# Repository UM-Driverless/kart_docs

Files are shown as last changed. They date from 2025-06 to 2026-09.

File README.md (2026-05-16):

# kart-docs

Documentation for the autonomous KART project.

📘 Live site: <https://um-driverless.github.io/kart-docs/>  
🧠 Main source: [Notion Kart Documentation](https://www.notion.so/KART-1b378747314380acb23ee354a4a4c4c7)

Built with [MkDocs](https://www.mkdocs.org/) using the [Material theme](https://squidfunk.github.io/mkdocs-material/).

---

## (Beta) Automated Installation
Just run `install.sh` in Linux or macOS:

## 🔧 Setup (using uv)

Install uv:

```bash
curl -LsSf https://astral.sh/uv/install.sh | sh
```

For other installation methods, see [uv documentation](https://docs.astral.sh/uv/getting-started/installation/).

---

Clone the repo and set up the project:

```bash
git clone git@github.com:UM-Driverless/kart-docs.git
cd kart-docs
uv sync
uv run playwright install --force chrome
```

This:
- Creates a virtual environment and installs dependencies
- Downloads a headless Chrome browser for PDF export

---

## ✅ Preview locally

```bash
uv run mkdocs serve
```
You can then access the documentation in your web browser, usually at `http://127.0.0.1:8000`.

To test the build before pushing (recommended):

```bash
uv run mkdocs build --strict
# Output: site/
```

The `--strict` flag will catch errors like broken links, missing files, and invalid configuration - the same checks that run in CI.

---

## 🚀 Deployment

Deployment to GitHub Pages happens automatically via GitHub Actions when you push to the `main` branch.

The workflow will:
1. Build the documentation with `--strict` flag
2. Deploy to GitHub Pages if the build succeeds
3. Site will be available at: https://um-driverless.github.io/kart-docs/

### Manual deployment (alternative)

If needed, you can still deploy manually:

```bash
uv run mkdocs gh-deploy
```

---

## 🤖 LLM-Friendly Documentation

This documentation includes LLM-optimized formats following the [llms.txt standard](https://llmstxt.org/):

- **llms.txt**: Sitemap-style overview of all documentation pages
- **llms-full.txt**: Complete documentation content in one consumable file

These files are automatically generated during the build process and are available at:
- Live site: https://um-driverless.github.io/kart-docs/llms.txt
- Live site: https://um-driverless.github.io/kart-docs/llms-full.txt

### Manual Generation

To manually generate the LLM files:

```bash
uv run python generate_llm_files.py
```

---

## 📊 BOM Reports & Parts Management

This documentation includes advanced BOM (Bill of Materials) management features:

### Automatic Features (Built into MkDocs)

When you build the docs, the following happens automatically:

- **Searchable parts table** - Dynamically generated from all `bom.yaml` files
- **Cost summaries** - Total costs by assembly, status, and criticality
- **Filterable by** - Assembly, status, category, or search text
- **Sortable columns** - Click any column header to sort

These features are enabled by the `generate_bom_hook.py` MkDocs hook.

### Manual BOM Reports

Generate comprehensive reports (JSON + CSV):

```bash
./generate_bom_reports.sh
```

Or manually:

```bash
uv run python scripts/aggregate_bom.py --output-dir reports/bom --format both
```

**Outputs:**
- `reports/bom/bom_complete_report.json` - Complete data (costs, suppliers, status)
- `reports/bom/bom_assembly_costs.csv` - Cost breakdown by assembly
- `reports/bom/bom_all_components.csv` - All components in spreadsheet format

### Adding Components

1. Navigate to appropriate assembly folder: `docs/assembly/steering/`
2. Edit `bom.yaml` file
3. Add component using YAML format
4. Component automatically appears in searchable table on next build

See the **[BOM page](https://um-driverless.github.io/kart-docs/bom/)** for complete documentation and searchable parts table.

---

## 📟 PDF Export (optional)

PDF export is disabled by default to speed up builds. To export PDFs explicitly:

```bash
EXPORT_PDF=true uv run mkdocs build
# Outputs: site/pdf/kart-documentation.pdf
```

---

## 🗂 Branch structure

- `main` → Markdown source (all edits go here)
- `gh-pages` → Legacy deployment branch (can be deleted if using GitHub Actions)

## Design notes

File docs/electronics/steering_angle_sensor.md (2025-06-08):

# Steering Angle Sensor
Sensor used is the cheap AS5600
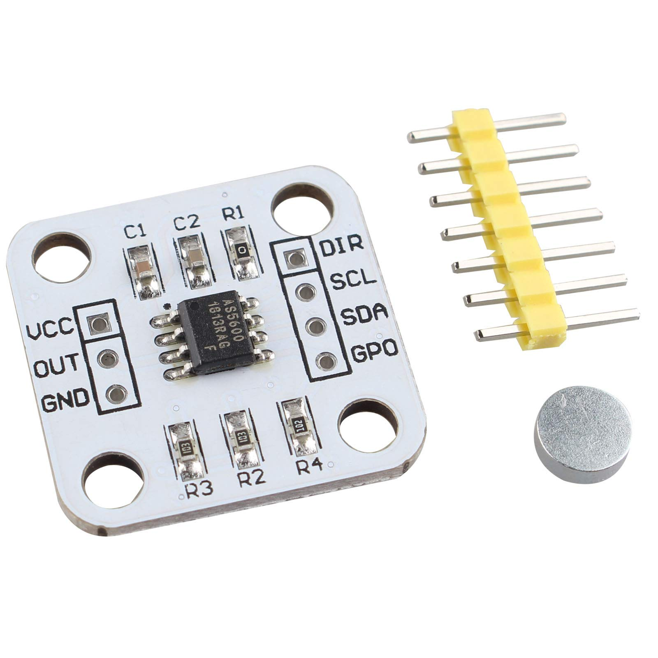
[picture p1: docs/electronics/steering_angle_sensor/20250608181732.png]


Intended for use with a diametrically magnetized magnet, but works with a normal one turned 90 degrees too.
It may be a good idea to find bigger neodymium diametric magnets.

Repo with basic code to read the steering angle sensor (Arduino HAL with VSCode Platformio, no IDE): https://github.com/rubenayla/bluepill-angle-arduino.git

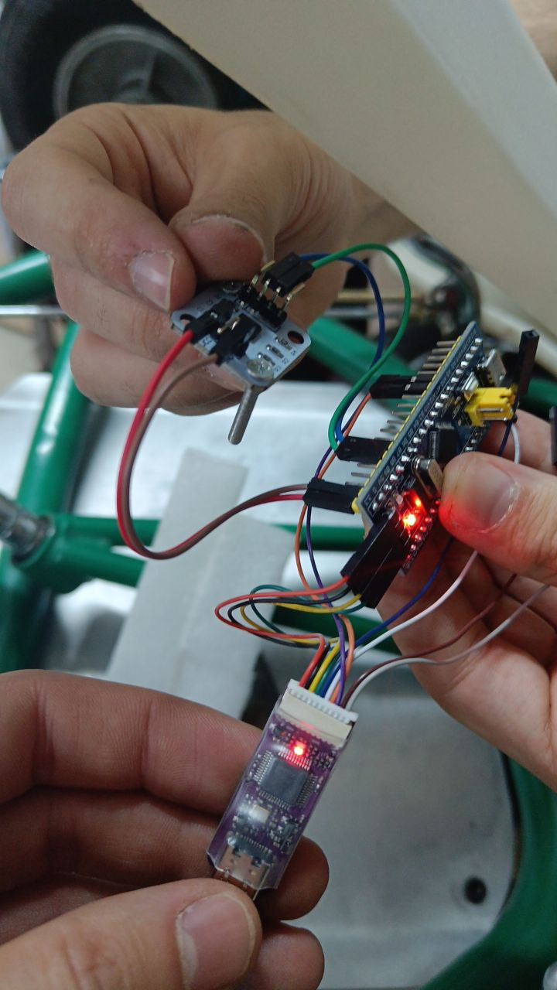
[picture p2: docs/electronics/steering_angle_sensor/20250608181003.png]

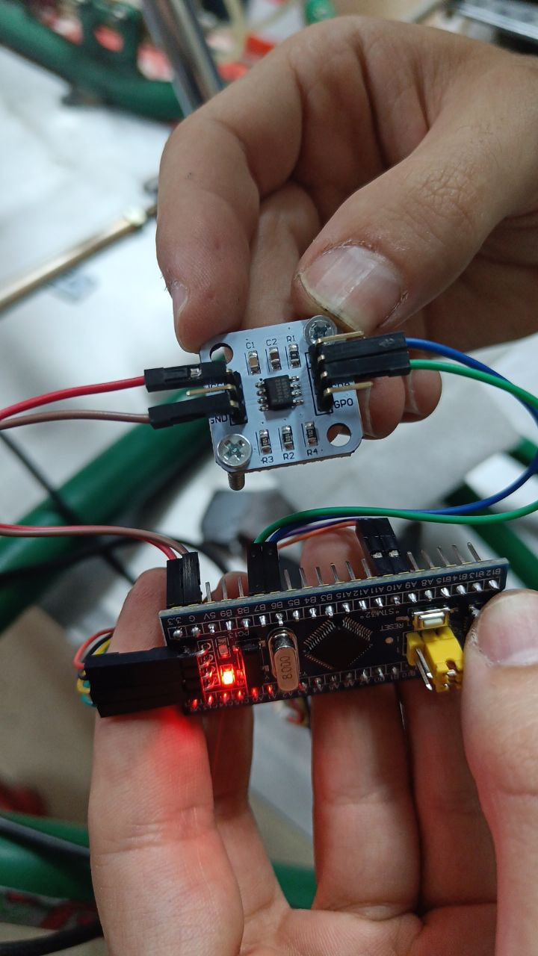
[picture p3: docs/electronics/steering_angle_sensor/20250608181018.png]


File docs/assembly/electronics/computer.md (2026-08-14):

# Computer

The kart's onboard computer is an **NVIDIA Jetson AGX Orin Developer Kit**. It runs the ROS 2 stack:
perception, planning, control, and the dashboard. It does not touch the actuators directly — it
sends commands over USB serial to the [Kart Medulla](kart-medulla/index.md), which does.

Flashing, JetPack versions, NVMe boot and the whole software install are on the
[Orin Setup](orin-setup.md) page. This page covers the hardware: what the board is, how it is
powered, and the adapter board that connects it to the kart.

## Specifications

| | |
|---|---|
| CPU | 12-core ARM (aarch64), 62 GB RAM |
| GPU | Ampere, CUDA 12.6 |
| Storage | 57 GB eMMC (soldered, bootloader only) + 476 GB NVMe M.2 SSD (root filesystem) |
| Power mode | `MODE_50W` — the board defaults to 30 W and is deliberately switched up |

## Power

| | |
|---|---|
| Voltage range | 9–20 V DC, typically 19 V |
| Supplied from | The kart's 12 V rail — see [Battery](power/battery.md) |
| Connector | Barrel jack, 5.5 mm OD / 2.5 mm ID, centre positive |

Measured power draw under load has not been recorded yet; the 50 W power mode is the ceiling the
board is configured for, not a measurement.

## Reference links

- [Jetson AGX Orin Developer Kit user guide](https://developer.nvidia.com/embedded/learn/jetson-agx-orin-devkit-user-guide/developer_kit_layout.html)
- [NVIDIA Jetson downloads and datasheets](https://developer.nvidia.com/embedded/downloads)

## Orin adapter board (v1.0)

A small custom PCB that breaks the Orin's 40-pin header out to the kart. Designed in
[EasyEDA](https://easyeda.com/); project file
[here](computer/images/ProProject_Orin Adapter_2025-03-09.epro), also in the Owncloud folder at
`formula/formula 24-25/DV/ORIN/adapter/ProProject_Orin Adapter_2025-03-09.epro`.

What the schematic contains:

- **Power supply:** regulated 3.3 V and 5 V outputs.
- **CAN interface:** an SN65HVD232DR transceiver. **Fitted but unused** — the kart has no CAN bus;
  the Orin ↔ medulla link is USB serial.
- **Connector:** 2.54 mm 2×20 header to the Orin.
- **Filtering:** C1 (47 nF), C2 (100 nF).
- **Resistors:** R1, R2 (60 Ω), R3, R_T (330 Ω), R4 (30 Ω).
- **Test points:** T1, T2.

### Schematic

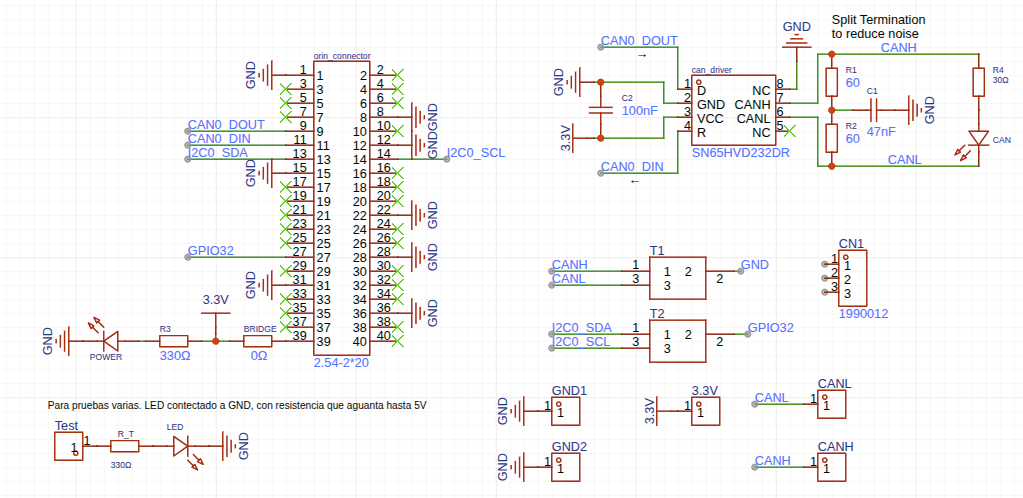
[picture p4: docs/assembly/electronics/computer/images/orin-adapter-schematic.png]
Orin Adapter Board Schematic


### Bill of materials

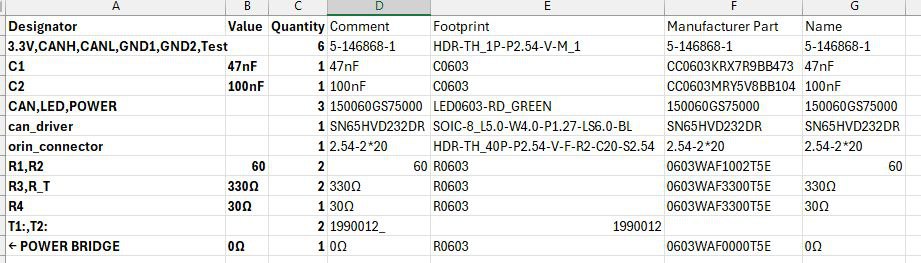
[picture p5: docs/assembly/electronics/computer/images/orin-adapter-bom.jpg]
Orin Adapter Board BOM


### Board

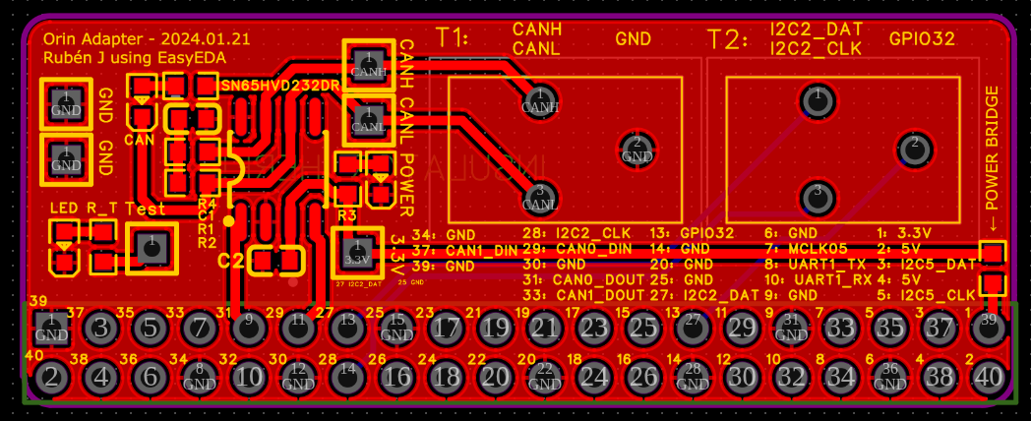
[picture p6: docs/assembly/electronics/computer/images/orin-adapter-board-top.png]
PCB Board Top View


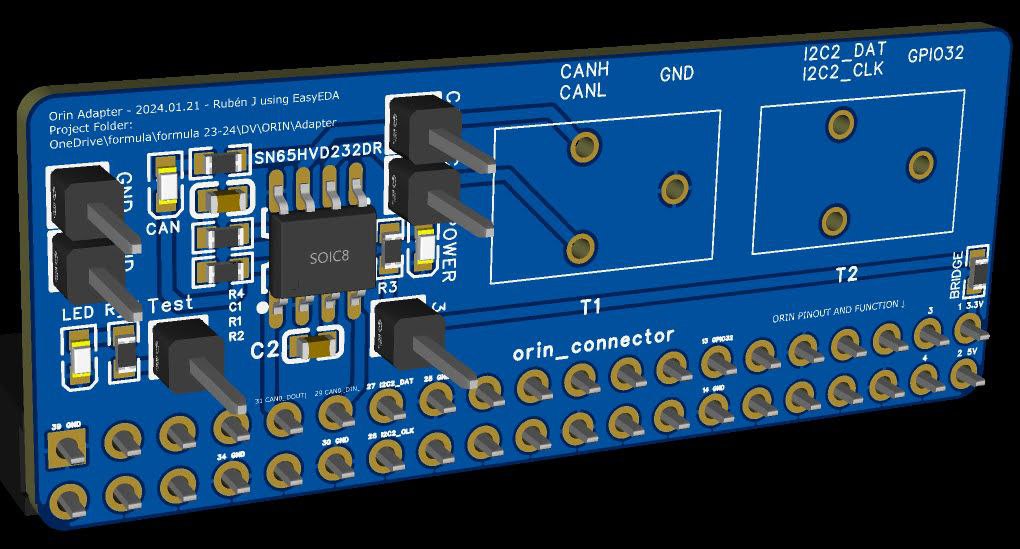
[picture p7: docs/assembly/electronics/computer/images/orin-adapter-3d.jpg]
Orin Adapter Board 3D View


## Installing AnyDesk on the Orin

For remote desktop access to the Jetson:

```bash
wget -qO - https://keys.anydesk.com/repos/DEB-GPG-KEY | sudo apt-key add -
echo 'deb http://deb.anydesk.com/ all main' | sudo tee /etc/apt/sources.list.d/anydesk.list
sudo apt update
sudo apt install -y anydesk
```

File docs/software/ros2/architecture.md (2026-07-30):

# Architecture

## Operating Modes

The system has two modes that share the same perception interface (`/perception/cones_3d`). A controller node doesn't know whether it's running in simulation or on real hardware.

### Simulation Mode

```
┌──────────────────────────────────────────────────────────────┐
│  Gazebo Fortress (headless)                                  │
│                                                              │
│  Physics (ODE) ──► Ackermann steering ──► Odometry           │
│                         ▲                    │               │
│                         │                    │               │
│  RGBD Camera (10Hz) ────│────────────────────│───────────    │
└─────────────────────────│────────────────────│───────────────┘
                          │             ros_gz_bridge
                   /kart/cmd_vel               │
                          │                    ▼
                          │         /model/kart/odometry
                          │                    │
                          │                    ▼
                          │         ┌─────────────────────┐
                          │         │ perfect_perception   │
                          │         │ (reads SDF + odom)   │
                          │         └──────────┬──────────┘
                          │                    │
                          │        /perception/cones_3d
                          │                    │
                          │                    ▼
                          │         ┌─────────────────────┐
                          └─────────│ cone_follower        │
                                    │ (midpoint steering)  │
                                    └─────────────────────┘
```

### Real Hardware Mode (Autonomous)

```
┌──────────┐
│ ZED 2    │── RGB + Depth + CameraInfo
│ Camera   │
└──────┬───┘
       │
       ▼
┌──────────────────┐     /perception/     ┌──────────────────────┐
│ yolo_detector    │──── cones_2d ──────►│ cone_depth_localizer  │
│ (YOLOv11,PyTorch)│                      │ (2D → 3D projection) │
└────────┬─────────┘                      └──────────┬───────────┘
         │                                           │
  /perception/yolo/                       /perception/cones_3d
     annotated                                       │
         │                                           ▼
         ▼                                ┌─────────────────────┐
┌──────────────────┐                      │ cone_follower       │
│ steering_hud     │                      │ (geometric/neural)  │
│ (overlay + gauge)│                      └──────────┬──────────┘
└────────┬─────────┘                                 │
         │                                    /kart/cmd_vel
  /perception/hud                                    │
         │                                           ▼
         ▼                                ┌─────────────────────┐
┌──────────────────┐                      │ cmd_vel_bridge      │
│ rqt_image_view   │                      │ (Twist → Frames)    │
│ (GUI window)     │                      └──────────┬──────────┘
└──────────────────┘                                 │
                                          /orin/throttle|brake|steering
                                                     │
                                                     ▼
┌──────────────────┐   /esp32/*      ┌───────────────────────┐    UART       ┌────────────┐
│ kb_dashboard     │◄──(Frame)──────│ kb_coms_micro         │◄────────────►│ ESP32      │
│ (web UI :80)     │                │ (serial bridge)       │  115200 8N1   │ (Medulla)  │
└──────────────────┘   /orin/*       └───────────────────────┘  int32 frames └────────────┘
```

### Real Hardware Mode (Teleop)

```
┌──────────┐          ┌──────────────────┐              ┌─────────────────┐
│ Gamepad  │──/joy──►│ joy_to_cmd_vel    │─/kart/cmd_vel─►│ cmd_vel_bridge  │
└──────────┘          └──────────────────┘              └────────┬────────┘
                                                                │
                                                         /orin/* (Frame)
                                                                │
                                                                ▼
                                               ┌───────────────────────┐    UART        ┌────────────┐
                                               │ kb_coms_micro         │──────────────►│ ESP32      │
                                               │ (serial bridge)       │  115200 8N1    │ (Medulla)  │
                                               └───────────────────────┘  int32 frames  └────────────┘
```

## Topic Map

### Simulation Topics

| Topic | Message Type | Publisher | Subscriber |
|---|---|---|---|
| `/clock` | `rosgraph_msgs/Clock` | Gazebo (bridged) | All nodes (`use_sim_time`) |
| `/model/kart/odometry` | `nav_msgs/Odometry` | Gazebo (bridged) | `perfect_perception` |
| `/kart/cmd_vel` | `geometry_msgs/Twist` | `cone_follower` | Gazebo (bridged) |
| `/zed/.../rgb/image_rect_color` | `sensor_msgs/Image` | Gazebo camera (bridged + remapped) | `yolo_detector` |
| `/zed/.../depth/depth_registered` | `sensor_msgs/Image` | Gazebo camera (bridged + remapped) | `cone_depth_localizer` |
| `/zed/.../rgb/camera_info` | `sensor_msgs/CameraInfo` | Gazebo camera (bridged + remapped) | `cone_depth_localizer` |

### Perception Topics (shared)

| Topic | Message Type | Publisher | Subscriber |
|---|---|---|---|
| `/perception/cones_2d` | `vision_msgs/Detection2DArray` | `yolo_detector` | `cone_depth_localizer` |
| `/perception/cones_3d` | `vision_msgs/Detection3DArray` | `cone_depth_localizer` or `perfect_perception` | Controller, `cone_marker_viz_3d` |
| `/perception/cones_3d_markers` | `visualization_msgs/MarkerArray` | `cone_marker_viz_3d` | RViz |
| `/perception/yolo/annotated` | `sensor_msgs/Image` | `yolo_detector` | `steering_hud`, RViz (debug) |
| `/perception/hud` | `sensor_msgs/Image` | `steering_hud` | `rqt_image_view` |

### Real Hardware Topics

| Topic | Message Type | Publisher | Subscriber |
|---|---|---|---|
| `/joy` | `sensor_msgs/Joy` | `joy_node` | `joy_to_cmd_vel` |
| `/kart/cmd_vel` | `geometry_msgs/Twist` | `cone_follower` | `state_machine`, `steering_hud` |
| `/kart/cmd_vel_muxed` | `geometry_msgs/Twist` | `state_machine` | `cmd_vel_bridge` |
| `/orin/throttle`, `/orin/brake`, `/orin/steering` | `kb_interfaces/Frame` | `cmd_vel_bridge` | `kb_coms_micro` |
| `/orin/machine_state`, `/orin/mision`, `/orin/steer_mode` | `kb_interfaces/Frame` | `state_machine` | `kb_coms_micro` |
| `/esp32/*` (speed, steering, health, heartbeat, …) | `kb_interfaces/Frame` | `kb_coms_micro` | `kb_dashboard` |
| `/battery/state` | `sensor_msgs/BatteryState` | `kb_bms` | `kb_dashboard` |
| `/perception/hud` | `sensor_msgs/Image` | `steering_hud` | `rqt_image_view` |

There is no single `/esp32/tx` + `/esp32/rx` pair — `kb_coms_micro` exposes one ROS topic per signal (see [Packages → kb_coms_micro](packages.md#kb_coms_micro)).

## TF Frame Tree

```
odom
 └── base_link              (kart chassis center)
      └── camera_link       (front-mounted camera)
```

- In simulation: `perfect_perception_node` broadcasts all transforms from odometry
- On real hardware: the ZED ROS wrapper and `robot_state_publisher` handle TF

## Message Flow

The autonomous driving loop, whether in simulation or on real hardware, follows these steps:

1. **Sense** — Camera (real ZED or simulated Gazebo) produces RGB + depth images
2. **Detect** — YOLO finds 2D cone bounding boxes, or `perfect_perception` uses ground truth
3. **Localize** — Depth image projects 2D boxes into 3D positions in camera frame
4. **Decide** — Controller separates blue (left) and yellow (right) cones, computes steering target
5. **Act** — `Twist` sent to Gazebo via `ackermann_to_vel` (sim), or split into `/orin/throttle|brake|steering` int32 Frames and sent to the ESP32 via `kb_coms_micro` (real)
6. **Feedback** — ESP32 sends telemetry (steering angle, health, heartbeat) back over the same framed int32 protocol; `kb_coms_micro` republishes it on `/esp32/*` for the dashboard

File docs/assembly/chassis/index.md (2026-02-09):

# Chassis

## Model Identification
Based on the frame markings (`TONY KART EXTREME`, `CIK ICA 330/99`), the chassis is identified as:

- **Make:** Tony Kart (OTK Kart Group)
- **Model:** Extreme
- **Era:** Late 90s / Early 2000s (1999 Homologation)
- **Type:** Competition Kart (ICA/ICC classes)
- **Tubing:** Green (Verde Tony), typically 30mm/32mm Chrome Moly tubing.
- **Axle:** 40mm (Confirmed by sprocket mount specs in powertrain docs).

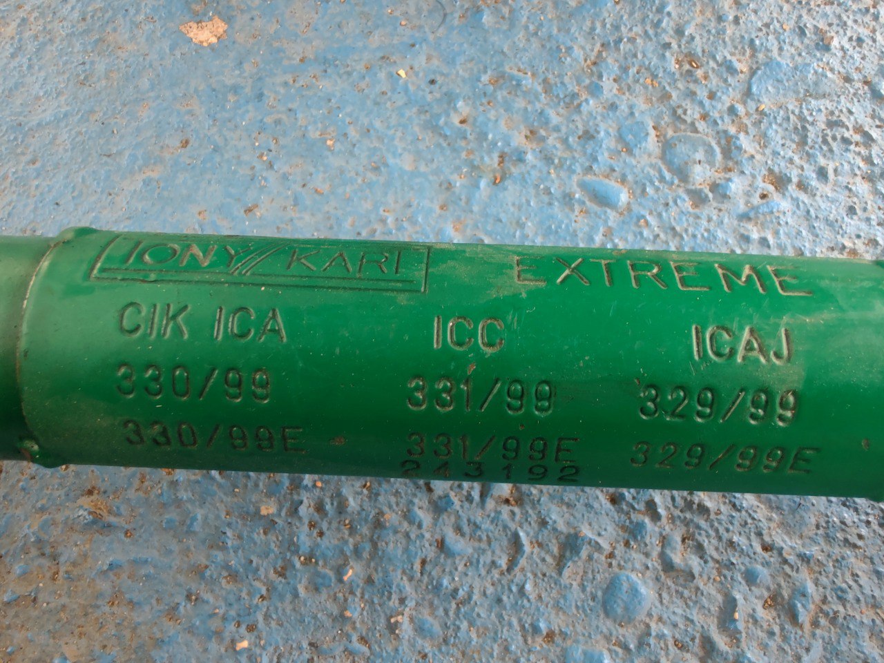
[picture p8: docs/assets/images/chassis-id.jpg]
Chassis ID


## Setup Reference

### Tire Pressure
Tire pressure is determined by the **tire model**, not just the chassis. However, for a standard racing kart setup (~150kg total weight with driver/robot):

| Tire Type | Cold Pressure (Bar) | Cold Pressure (PSI) | Notes |
|---|---|---|---|
| **Soft/Medium Slicks** | 0.75 ± 0.1 | ~11 ± 1.5 | Standard racing range (e.g., Vega Green/White) |
| **Hard Slicks** | 0.90 ± 0.1 | ~13 ± 1.5 | Endurance or rental compounds |
| **Rain Tires** | 1.20 ± 0.2 | ~17.5 ± 3 | Higher pressure to open treads |

> **Tip:** For autonomous runs, consistency is key. Start at **0.8 bar (11.6 psi)** all around and adjust based on tire wear and grip levels.

### Maintenance
- **Bearings:** Check rear axle bearings (3 per side usually) and front stub axle bearings.
- **Alignment:** The Extreme has adjustable caster/camber pills at the front kingpins. Neutral setting is recommended for initial autonomous testing.

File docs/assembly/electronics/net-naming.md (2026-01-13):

# Net Name Nomenclature

This document defines a simple, consistent naming scheme for all nets/signals in the PCB and system. Goal: no ambiguity, easy to read, applicable to cables/connectors.

Names describe the signal's purpose and type. Apply consistently across schematics, cables, and docs. If a signal changes, rename it—no over-future-proofing.

## Structure
Every name: `DESCRIPTOR[_NUMBER_OR_SPECIFIER]__INTERFACE`

- `DESCRIPTOR`: Signal's primary purpose (e.g., `PEDAL_ACC`, `CMD_BRAKE`, `RES_PRESSURE`).
- `NUMBER_OR_SPECIFIER`: For multiples/clarification (e.g., `1`, `2`, `3`, `DIR`, `SDA`, `SCL`, `LOW_SIDE`). Omit if unnecessary.
- `INTERFACE`: Electrical type (e.g., `__0_5V`, `__PWM_3V3`). Include voltage/range explicitly where relevant (e.g., for PWM or logic levels).

No direction words (`IN`, `OUT`, `RX`, `TX`)—descriptor implies flow. Use uppercase, underscores only.

## Allowed Descriptors (based on this PCB)
- `PEDAL_ACC`: Accelerator pedal input.
- `PEDAL_BRAKE`: Brake pedal input.
- `CMD_ACC`: Accelerator command output.
- `CMD_BRAKE`: Brake command output.
- `RES_PRESSURE`: Air reservoir pressure measurement.
- `WHEEL_HALL`: Wheel hall sensor pulse (for speed derivation).
- `CMD_STEER`: Steering command (with specifier like `DIR` or `PWM`).
- `I2C_STEER`: I2C bus for steering.
- `SDC_ENABLE`: Safety/shutdown enable (or `SDC_STAT`/`SDC_FLT` if different).

## Interface examples
`__0_5V` | `__0_10V` | `__5V` | `__3V3` | `__PWM_3V3` | `__PWM_5V` | `__PWM_12V` | `__I2C` | `__12V`

## Examples
`PEDAL_ACC__0_5V` (Accelerator from pedal to ESP32)  
`CMD_BRAKE__0_10V` (Brake command from ESP32 to valve)  
`RES_PRESSURE_1__0_10V` (First reservoir pressure sensor)  
`WHEEL_HALL_2__5V` (Second wheel hall pulse)  
`CMD_STEER_DIR__3V3` (Steering direction command)  
`CMD_STEER__PWM_3V3` (Steering PWM command)  
`I2C_STEER_SDA__I2C` (I2C data line for steering)  
`SDC_ENABLE_LOW_SIDE__12V` (Safety enable via low-side switch)

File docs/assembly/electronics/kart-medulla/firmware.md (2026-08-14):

# Kart Medulla Firmware

The firmware side of the Kart Medulla ESP32 — the software that receives commands from the Orin, runs the steering PID loop, and drives the throttle/brake/steering actuators. The board itself, its pinout, and the wiring live on the [Kart Medulla](index.md) page; this page covers how the firmware is built and how it is structured.

**Repository:** [UM-Driverless/kart-medulla](https://github.com/UM-Driverless/kart-medulla)

## Framework and build environments

- **Framework:** ESP-IDF (5.x) via **PlatformIO**, platform pinned to `espressif32@6.4.0`. The firmware is bare-metal FreeRTOS with no ROS dependency — its own toolchain and flashing process, deliberately decoupled from the Orin's ROS 2 workspace.
- **Build environments** in `platformio.ini`:

| Env | Board | Purpose | State |
|---|---|---|---|
| `esp32-s3-devkitc-1` | `esp32-s3-devkitc-1` | **ESP32-S3 — the kart's MCU. This is the image that runs on the kart.** | Working — builds and uploads from the Orin |
| `esp32dev` | `esp32dev` | Classic ESP32-WROOM-32E. Kept as a fallback only; not flashed to the kart | Present in `platformio.ini`, never built on the Orin |
| `native` | – | Host-side unit tests with hardware fakes | Working |

The classic and S3 chips are not interchangeable images — the classic ESP32 is Xtensa LX6 and the S3 is LX7, so an `esp32dev` binary will not boot on the kart's board and `esptool` rejects the chip-ID mismatch. The two envs are separate targets, not two ways of building the same thing.

`components/km_gpio/km_gpio.h` carries **both** pin maps and picks between them at compile time on `#if defined(CONFIG_IDF_TARGET_ESP32S3)`. Building the `esp32-s3-devkitc-1` env takes the S3 branch: `PIN_STEER_PWM` = GPIO 40, `PIN_STEER_DIR` = GPIO 17, `PIN_SDC_NOT_EMERGENCY` = GPIO 18. The classic map — where `PIN_STEER_PWM` is GPIO 18, which on the S3 board is the gate of Q3, the shutdown-circuit MOSFET — sits in the `#else` and is not compiled. That overlap is why the two must never be mixed up: reasoning from the wrong branch can fire or disable the emergency brake.

The schematic in `dv-hardware` is the authority on any pin claim, with `dv-hardware/projects/kart-medulla/docs/pinout-esp32-s3.md` as its readable form. This page does not restate the pin map — see the [Kart Medulla](index.md) board page and the [CN connector pinout](pinout.md).

## Building and flashing

!!! danger "De-power the steering before any flash"
    Flashing hard-resets the ESP32 into the download bootloader, and for that whole window `CMD_STEER_PWM` (GPIO 40) and `CMD_STEER_DIR` (GPIO 17) float — neither has a pulldown, unlike GPIO 3 and GPIO 18 — while the Cytron H-bridge stays powered from the 48 V pack. The steering motor can then drive uncontrolled. This swung the steering to full lock and **broke teeth off the steering gears on 2026-08-08**.

    De-power the Cytron or unplug the steering motor before flashing, or have the kart in manual with actuator power off. No firmware change can cover this — the firmware is not running during that window. The permanent fix is a pulldown on `CMD_STEER_PWM`, tracked as REQ-08 in `dv-hardware/projects/kart-medulla/requirements.md`.

Flashing happens **from the Orin**, which is where the ESP32 is plugged in. The Mac can compile-check a change first — PlatformIO is installed there at `~/.platformio/penv/bin/pio` (not on `PATH`, so call it by full path) and builds both envs to a linked binary — but the board is on the Orin, so that is where uploads happen. The `kart-brain` service holds the serial port, so it has to be stopped first and restarted afterwards:

```bash
ssh orin-remote 'echo 0 | sudo -S systemctl stop kart-brain'
ssh orin-remote 'cd ~/kart_medulla && ~/.local/bin/pio run -e esp32-s3-devkitc-1 --target upload --upload-port /dev/ttyACM0'
ssh orin-remote 'echo 0 | sudo -S systemctl start kart-brain'
```

```bash
# Serial monitor
pio device monitor

# Run unit tests on the host (no hardware needed)
pio test -e native
```

- **Port:** the S3 enumerates on the Orin as **`/dev/ttyACM0`** — the CH343 is a CDC-ACM device. It is *not* `/dev/ttyUSB0`; that was the classic board's CP2102.
- **USB bridge:** WCH **CH343** (`lsusb` → `1a86:55d3`, "QinHeng Electronics USB Single Serial"). On macOS the same board appears as `/dev/cu.usbmodem*`. The S3's two USB-C ports are silkscreened `COM` (the bridge) and `USB` (native USB-OTG / USB-Serial-JTAG).
- **Upload baud:** `platformio.ini` sets `upload_speed = 921600` for the S3 env. The old 115200 cap belonged to the *classic* board's CP2102 and does not apply to the CH343 (rated to 6 Mbps). Confirmed on hardware — the 2026-08-10 flash from the Orin wrote 338 kB in 2.6 s, about 1.05 Mbit/s effective, hash verified. If a flash ever fails to connect or fails verification, try 460800, then 115200.
- **BOOT-button recovery:** if a flash hangs at `Connecting...`, hold **BOOT**, press **EN**, release **BOOT**; press **EN** afterwards to restart if needed.

Source: `kart-medulla/README.md`, `kart-medulla/AGENTS.md`.

## FreeRTOS task architecture

The firmware runs four FreeRTOS tasks. The period argument in the task-creation calls is in **milliseconds**, not Hz — a detail worth knowing before reading `main.c`.

| Task | Period → rate | Stack | Priority | Role |
|---|---|---|---|---|
| `comms` | 10 ms → 100 Hz | 4096 B | 2 | UART RX/TX — receive commands from the Orin, send telemetry |
| `control` | 2 ms → 500 Hz | 4096 B | 1 | Read the steering angle, run the PID, drive the actuators, decide the shutdown circuit, apply the comms/manual safety, send steering feedback |
| `heartbeat` | 1000 ms → 1 Hz | 2048 B | 1 | Send a heartbeat to the Orin |
| `health` | 1 Hz | 4096 B | 1 | Monitor sensor / I²C / heap and report to the Orin. Started with its own `xTaskCreate`, not via the `KM_RTOS` periodic wrapper |

500 Hz is measured on the kart (the `control_iters` field of the `ESP_PNEUMATIC` telemetry frame counts it), not just a target. Nothing in the loop blocks: the steering sensor is read through hardware MCPWM capture rather than an I²C transaction. The rate cap is the UART — the per-cycle steering frame uses about 87 % of the 115200-baud link and TX is unbuffered.

Source: `main/main.c`, `system_init()`.

### Firmware components

The tasks are built from components under `components/`:

| Component | Role |
|---|---|
| `km_coms` | UART framed binary protocol to/from the Orin |
| `km_rtos` | FreeRTOS periodic-task manager |
| `km_pid` | PID controller |
| `km_sdir` | Steering angle sensor. `km_sdir_pwm` decodes the MT6701's PWM output through MCPWM capture — this is the kart's path. The AS5600 I²C driver in the same component is the classic-board fallback |
| `km_gpio` | GPIO / ADC / DAC / PWM / I²C hardware abstraction (holds the pin map) |
| `km_act` | Actuator control (DAC throttle/brake, PWM+DIR steering) |
| `km_objects` | Thread-safe shared object store (targets, actuals) |
| `km_sta` | State machine |
| `km_gamc` | Gamepad controller (Bluepad32) |

## Steering PID pipeline

The steering control path, per `control_task` in `main/main.c`:

1. The Orin sends a target steering angle over the serial protocol.
2. `control_task` reads the target from the `km_objects` store.
3. The **MT6701** angle sensor is read from its ~994 Hz PWM output on GPIO 1, captured in hardware by MCPWM → actual angle in radians. Positive = left already, matching the body-frame convention, so no negation. The sensor is on CN5.2, the terminal originally labelled Pressure 3.
4. `km_pid` computes an output in `[-1.0, 1.0]`.
5. `km_act` drives the steering motor: PWM duty = magnitude, DIR pin = sign, into the Cytron H-bridge.
6. The actual angle is sent back to the Orin as steering feedback.

There is also a **direct-PWM mode** (`STEER_MODE = 1`): the target is interpreted straight as a PWM value in `[-1.0, 1.0]` and the PID is bypassed (its integral is reset so it does not wind up while inactive). Default is PID mode.

### Gains

The compiled defaults are `PID_DEFAULT_KP` / `KI` / `KD` / `PWM_LIMIT` at the top of `main/main.c`: **Kp = 1.00, Ki = 0.0, Kd = 0.05, output limit 0.50**. The limit is deliberately held below 100 % to protect the steering gears during testing; raise it as the loop is validated.

These are being actively tuned, so read them from `main.c` rather than from any table when the exact value matters. The Orin can also override all four at runtime with the `ORIN_STEER_PID` (0x2B) frame; the firmware reports what it is actually running back in `ESP_STEER_PID` (0x0D), which is what the dashboard displays. A dashboard value that differs from the numbers above means an override is live, not that something is wrong.

## Orin ↔ ESP32 protocol

The framed binary serial protocol between the Orin and the ESP32 (message types, encoding, CRC) is **not re-specified here** to avoid two copies drifting apart. See the canonical protocol reference on the [ROS 2 packages](../../../software/ros2/packages.md) page. In short: it is a plain **USB serial** link (UART over the USB bridge) — there is no CAN anywhere on the kart.

## Comms-loss watchdog (safety-relevant)

A comms watchdog runs inside `control_task` with `COMMS_WATCHDOG_MS = 1000`. If no command has arrived within that window **or** the mission is `MISSION_MANUAL`, the firmware hands the throttle mux back to the driver's pedal, calls `KM_ACT_Stop()` on throttle, brake **and** steering, and resets the PID.

**By design, losing comms brakes the kart** — but not through the actuator outputs above. `KM_ACT_Stop()` **zeroes** them, and zeroing the brake command **releases** the proportional valve. The stop comes from the shutdown circuit instead: fresh comms is one of the conditions that keeps the chain closed, so a timeout opens it and fires the EBS. That route was chosen over commanding a brake value because it does not depend on the Orin still being able to talk, and it reuses the path an emergency already takes.

!!! danger "Today the kart coasts — the shutdown-circuit gate is not wired"
    The firmware already opens the chain on stale comms. It fires nothing, because Q3's gate is not connected to anything downstream (see [Shutdown circuit](#shutdown-circuit-sdc) below). **Until that wire exists, a comms timeout leaves the kart coasting.**

    `kart-brain/docs/ACTUATION_PROTOCOL.md` specifies "apply full brake, zero steering, zero throttle" on timeout. That is the intended behaviour and the mechanism above is how it is delivered — but do not rely on it for safety yet. Wiring the gate is tracked in `kart-brain/tasks.md`, "Verify the shutdown-circuit drive on the bench, then wire the Q3 gate".

    Source: `main/main.c` (`control_task`), `kart-brain/docs/ACTUATION_PROTOCOL.md`.

## Shutdown circuit (SDC)

`control_task` decides the level of the shutdown-circuit line, GPIO 18 — the gate of Q3 — on every 2 ms cycle. It is written as a **whitelist**: the chain closes only while *all* of these hold, and opens in every other case, including states nobody anticipated.

- The Orin reports `AS_READY` or `AS_DRIVING`. `AS_OFF`, `AS_FINISHED` and `AS_EMERGENCY` all leave it open, so the ESP32 never arms the kart on its own initiative — the Orin has to keep asking, every cycle.
- Comms are fresh (same watchdog as above).
- Tank pressure is above `EBS_TANK_ARM_BAR` = 6.5 bar, falling back below 6.0 bar to open it again. The hysteresis stops the line chattering while the tank sits on the threshold. An empty kart therefore sits in emergency until the compressor brings the tank up, which is how Formula Student expects it to behave.
- The steering-fault latch is clear.
- The operator has not disabled the compressor from the dashboard — a kart that cannot refill its EBS reservoir must not look ready to drive.

!!! warning "The gate is not wired downstream yet"
    Q3's gate does not connect to anything, so nothing physically brakes or arms when this line changes. Check the logic through the pin readback — field 8 of the `ESP_PNEUMATIC` telemetry frame, shown on the dashboard's EBS page — or with a meter on the pin. Do not check it by expecting the kart to react.

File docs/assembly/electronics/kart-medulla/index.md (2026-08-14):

# Kart Medulla (ESP32-S3)

The Kart Medulla is the MCU-based control hub between the Orin computer and the kart's sensors and actuators. It is an interface PCB built around the **ESP32-S3**, with external level shifting, analog conditioning, an SPI DAC, an on-PCB manual/autonomous signal mux, and Wago-style push-in connectors. This board is the one installed in the kart; the earlier hand-wired classic-ESP32 setup (ESP32-DevKitC V4, flying wires, no PCB) is retired and no longer documented here.

**Firmware repository:** [UM-Driverless/kart-medulla](https://github.com/UM-Driverless/kart-medulla)

## Why ESP32-S3

The classic ESP32 ran out of usable GPIOs once CAN, SPI, status RGB, buzzer, and the Orin link were added on top of the existing I/O (3× halls, 3× pressure, accelerator, brake, SDC — shutdown circuit — steering, relay). The S3 solves this and adds several quality-of-life wins:

- **~45 GPIOs** (vs ~34 on the classic), with fewer of them reserved or strap-pin traps.
- **Native USB-OTG** — makes a direct ~12 Mbit/s USB link to the Orin possible without a USB-UART bridge IC. Not what the kart runs today: the fitted DevKitC-1 carries a WCH CH343 bridge on its `COM` port and the Orin link goes over UART0 through it, at 115200 baud. The native port (silkscreened `USB`, on GPIO 19/20) is available if that link ever becomes the bottleneck — see [Firmware](firmware.md) for what switching cables changes.
- **Built-in USB-Serial-JTAG** — flashing, serial monitor, and step-debugging all over the same USB cable. No external ESP-Prog / FT2232H needed.
- **External DAC on the PCB** (MCP4922, dual 12-bit, SPI) — replaces the classic ESP32's built-in 8-bit DAC. 12-bit resolution × 2 channels covers `CMD_ACC` (accelerator, 0–5 V direct) and `CMD_BRAKE` (brake, 0–5 V → ×2 op-amp → 0–10 V for the Festo proportional valve) with no extra pin cost beyond the existing SPI bus.

Variants considered and rejected: **S2** (has DAC but single-core, no BT), **C3** (too few GPIOs), **C6** (no DAC, Wi-Fi 6 overkill for a kart), **H2** (no Wi-Fi).

## ESP32-S3 Overview

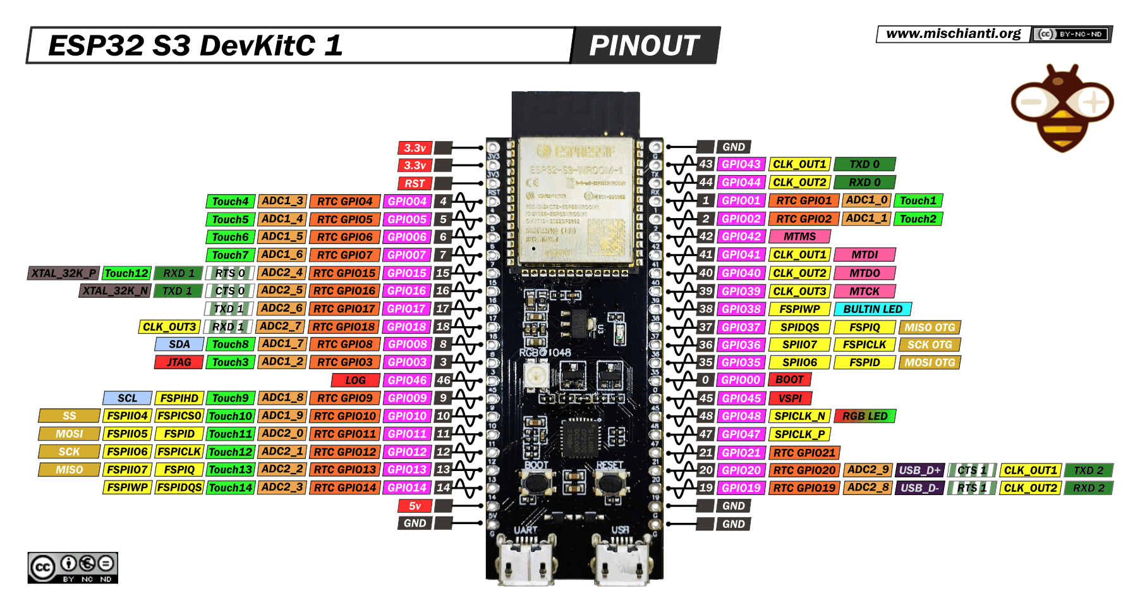
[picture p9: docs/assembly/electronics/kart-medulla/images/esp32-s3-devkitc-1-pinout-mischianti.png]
ESP32-S3-DevKitC-1 pinout (high resolution — click to open reference page) (https://mischianti.org/esp32-s3-devkitc-1-high-resolution-pinout-and-specs/)


*Click the image for the full high-resolution pinout and specs page at [mischianti.org](https://mischianti.org/esp32-s3-devkitc-1-high-resolution-pinout-and-specs/).*

- **CPU:** Xtensa dual-core 32-bit LX7, up to 240 MHz
- **GPIOs:** ~45 usable
- **ADCs:** 2× 12-bit, multi-channel
- **DACs:** none (external MCP4922 dual 12-bit SPI DAC on the interface PCB)
- **USB:** native USB-OTG + USB-Serial-JTAG
- **Wireless:** Wi-Fi 4 + BLE 5
- **Communication Interfaces:** SPI, I²C, UART, CAN (TWAI), I²S

## Dev-board mechanical reference (ESP32-S3-DevKitC-1)

The medulla PCB hosts the ESP32-S3 module via a stock **ESP32-S3-DevKitC-1** dev board (or a pin-compatible clone such as the YD-ESP32-S3 / "44 pines tipo C"). The medulla footprint must match this:

| Quantity | Value |
|---|---|
| Pin pitch (within a row) | **2.54 mm** (0.1 ″) |
| Pins per row | **22** (44 total — 2 rows of female sockets) |
| **Row centerline ↔ row centerline** | **22.86 mm** (0.9 ″) |
| PCB outer width | 25.40 mm (= 22.86 + 2 × 1.27 mm edge offset) |
| USB-C protrusion past board edge | ~8.00 mm |

**The row spacing is 22.86 mm (0.9 ″), NOT 25.40 mm.** Pin centerlines are inset 1.27 mm from each PCB edge. This is confirmed by physical caliper measurement on an official Espressif board (2026-05-02). The Espressif `DXF_…_V1.1_20220429.pdf` mechanical drawing has ambiguous `1.27 mm` callouts that can be read as either antenna keepout or pin-row offset, so **trust the physical measurement, not any single drawing.** Local mirrors of the Espressif drawing, schematic, and the ground-truth measurement photo are kept in the dv vault at `dv/kart/kart-medulla/resources/esp32-s3-devkitc-1/`.

## ESP32-S3 Pin Assignment

**The full 44-row pin table is not repeated here. It lives with the schematic**, in
[`projects/kart-medulla/docs/pinout-esp32-s3.md`](https://github.com/UM-Driverless/dv-hardware/blob/3da3b4655835a0bff6131b18d9e9947db73568ae/projects/kart-medulla/docs/pinout-esp32-s3.md)
(`dv-hardware`), because a pin map is only correct relative to a schematic revision and the two have
to change in one commit. This page carries what you need **with the board in front of you**: which
pins do something other than their name, and what has been physically modified.

A hand-maintained copy of that table used to sit here. It drifted — on 2026-07-30 someone reconciled
it row by row and left a note that two rows were deliberately ahead of dv-hardware; one day later
dv-hardware caught up and the note became wrong. That is why there is now one table, not two.

For the per-pin capability reference (which GPIOs can do ADC, which are strap pins) see
[`lib/esp32-s3-pin-capabilities.md`](https://github.com/UM-Driverless/dv-hardware/blob/c3e9dcc223ffe28ebb7667a7d0dcd2dbe9d412cb/lib/esp32-s3-pin-capabilities.md).

Pin numbers 1–44 follow a chip-style counter-clockwise convention: pin 1 is the bottom-right contact
(USB-C at the top, component side facing you), pins 1–22 climb the right edge, pins 23–44 descend the
left edge. **Use these numbers when probing or talking about a contact** — they are not the
schematic-symbol pin numbers. The medulla's left header is dual-row (44 pads, 22 unique nets — each
row is shorted between its two pads for daughterboard pass-through).

### What the assembled board actually does

Board `84d6dd0` (the gerber-export commit, written on the board itself). Deviations from the pin
table only — everything not listed does what the table says.

| Pin | GPIO | Terminal | Name on the schematic | What it actually does |
|---|---|---|---|---|
| 19 | 1 | CN5.2 | `PRESSURE_3` | Reads the steering-angle sensor's PWM |
| 35 | 3 | CN8.2 | `BUZZER` | Drives the EBS compressor MOSFET gate |

Both are permanent, and neither displaced anything: no pressure-3 sensor is fitted, and the kart
carries no buzzer or ASSI at all (those are formula-vehicle parts — settled 2026-07-18). The same two
rows, plus the planned throttle-PWM pin, are listed in the "As-built pin use" section of the
dv-hardware pinout file; **physical modifications are tracked in that board's rework list** in
[`projects/kart-medulla/README.md`](https://github.com/UM-Driverless/dv-hardware/blob/main/projects/kart-medulla/README.md).

!!! info "Two repurposed terminals on the current board"
    Detail for the two rows in the table above — what to do with a probe and a soldering iron. The firmware header `km_gpio.h` carries both (`PIN_STEER_PWM_IN` = GPIO 1, documented there as the MT6701's ~994 Hz PWM angle frame; `PIN_CMD_COMPRESSOR` = GPIO 3). The authoritative map is the schematic, with [`.agents/esp32s3-pinmap.md`](https://github.com/UM-Driverless/kart-medulla/blob/main/.agents/esp32s3-pinmap.md) as its firmware-side copy.

    - **CN5.2 / GPIO 1 — steering-angle PWM (was `PRESSURE_3`).** The Pressure-3 ADC channel is retired; the terminal now reads the steering-angle sensor's **single-wire PWM output — the wheel angle is encoded in the PWM duty cycle** — decoded on the ESP32-S3 with the MCPWM capture peripheral (edge timing), not read as an analog voltage. **Board rework: remove R10 only** (the pulldown to GND), keeping R8 + R9. The net is `CN5.2 —[R8 10k]— node —[R9 10k]— GPIO 1 —[R10 10k]— GND`, so R10 is the only shunt to ground and R8 + R9 stay in place as a 20 kΩ series into the pin — too high-impedance for the ADC, which is why this pin reads digital PWM (MCPWM capture), not analog. **This is the live path as of 2026-07-31: the MT6701 is mounted and validated working on the kart, reading over PWM** — it replaced the AS5600/I²C arrangement rather than waiting as a later cleanup. See [Angle Sensor](../../steering/sensor/index.md) and [Wiring](../wiring.md).
    - **CN8.2 / GPIO 3 — EBS compressor PWM (was `BUZZER`).** The old buzzer output now drives the EBS air-compressor MOSFET gate (net `CMD_COMPRESSOR_PWM`); the buzzer was dropped. An external 100 kΩ gate pulldown holds the FET off through boot.

!!! note "CMD_ACC and CMD_BRAKE go through the external SPI DAC"
    The classic ESP32 exposed `CMD_ACC` on a dedicated DAC pin. On the S3 there is no native DAC — both `CMD_ACC` and `CMD_BRAKE` are generated by the **MCP4922** (dual 12-bit SPI DAC, see hardware decisions below) and ride the existing SPI bus (CS = GPIO 14). Channel A → `CMD_ACC` (0–5 V direct), Channel B → `CMD_BRAKE` → ×2 op-amp → 0–10 V for the Festo proportional brake valve.

!!! note "GPIO restrictions (ESP32-S3)"
    Strap/boot pins on the S3 — notably GPIO 0, 3, 45, 46 — must be left at safe levels at reset; the table notes mark which assignments are constrained by this. On WROOM-1 modules some of GPIO 26–32 are tied to the SPI flash internally (always reserved). GPIO 33–37 are consumed by the octal PSRAM on the fitted module — see below.

!!! warning "Module fitted: ESP32-S3-WROOM-1-N16R8 — GPIO 33–37 are permanently unavailable"
    The module on the board is an **ESP32-S3-WROOM-1-N16R8** (16 MB flash, 8 MB **octal** PSRAM). Confirmed on the hardware: `esptool` reports `ESP32-S3 (QFN56) revision v0.2` with `Embedded PSRAM 8MB (AP_3v3)`, and the firmware repo records the same module in `AGENTS.md` and `.agents/esp32s3-pinmap.md`.

    **GPIO 33–37 must never be assigned.** On R8 modules the octal PSRAM die is hard-wired to those pins (the SPI0/1 extension pins) *inside the module package*, and Espressif's ESP32-S3-WROOM-1 datasheet marks them as not available. This is physical, not a firmware setting: disabling PSRAM in `sdkconfig` does **not** reclaim them, because the die stays electrically attached to the traces, and driving them externally risks bus contention during boot.

    The pinout above already respects this — GPIO 33, 35, 36, and 37 are all `HOLD` with no signal routed, and `CMD_REVERSE` lives on the U25 PCF8574 expander (port P0) rather than on GPIO 36. `MOTOR_HALL_1` was moved off GPIO 37 to GPIO 16 for the same reason. So the fitted R8 module costs the design nothing today; the constraint only bites if a future revision needs those five pins back.

    **Substituting a quad-PSRAM module is safe in the other direction.** An **N16R2** (16 MB flash, 2 MB quad PSRAM) or **N8R2** (8 MB flash, 2 MB quad PSRAM) is a drop-in that *frees* GPIO 33–37 rather than consuming them, with no pinout change. Going the other way — assigning any of GPIO 33–37 and then fitting an R8 — is what breaks.

    Historical note: N8R2 was the specified part from 2026-04-23 until 2026-07-30, and these docs previously carried a "do not buy R8" rule. An N16R8 was fitted instead, the pinout turned out to be R8-safe, and the rule was retired rather than the module swapped. Background in the dv vault, `kart/kart-medulla/history.md` (2026-04-23, 2026-04-29).

## Kart Medulla Interface PCB

Interface PCB hosting the ESP32-S3 module, signal conditioning, the SPI DAC, the manual/autonomous analog mux, and outside-world connectors. Design lineage (EasyEDA `.epro` project files) lives in the Drive folder `formula_24-25-26/dv/kart/kart-medulla/project-backups/`.

### Hardware Decisions

- **Shutdown circuit (SDC):** a single ESP32 GPIO — `SDC_NOT_EMERGENCY` on GPIO 18 (Pin 33) — drives the gate of Q3 (IRLZ44N) through R22 (100 Ω). When HIGH, Q3 conducts and pulls the kart's `SDC_IN_LOW_SIDE` to GND, completing the SDC return path → no emergency. When LOW, Q3 is off and the chain breaks → emergency. R23 (100 kΩ) gate-pulldown forces Q3 OFF (= emergency) at boot until firmware actively drives HIGH. The signal name reflects the *intent* the ESP32 asserts, not the chain's electrical state. There is no separate `SDC_STAT` readback in this rev — the ESP32 trusts its own command. (The previous design used a relay + a status pin on GPIO 38/39; replaced 2026-05-08 with the MOSFET-only scheme so the gate driver sits next to Q3 on the PCB layout.)
- **Analog command outputs (`CMD_ACC`, `CMD_BRAKE`):** external **MCP4922-E/SL** — dual 12-bit SPI DAC. On the existing SPI bus (CS = GPIO 14). VREF tied to the 5 V rail through a 100 Ω + 10 µF RC filter to attenuate ~150 kHz switching ripple from the upstream XW-1224 buck. Channel A → `CMD_ACC` 0–5 V direct; Channel B → `CMD_BRAKE` → ×2 op-amp → 0–10 V for the **Festo proportional brake valve**. Decision history: 2026-04-13 (initial choice was MCP4728 I²C) → 2026-04-17 (switched to MCP4922 SPI because we already had MCP4922 chips on hand and SPI is cleaner for an analog-command bus shared with no other slow devices).
- **Manual/autonomous signal mux (decision 2026-05-01, refined 2026-05-02 / 03 / 08):** **one** MAX4660EUA+T SPDT analog switch (U14) on the PCB muxes the **throttle** signal between the manual source and the ESP32 DAC output. **Brake is NOT muxed** — manual mode does not need brake control routed through the ESP32, so the brake DAC output goes directly to the brake valve driver with no switch (decision 2026-05-08). **Reverse is NOT muxed via MAX4660 nor via a direct ESP32 GPIO** — it is driven by **U25 PCF8574T port P0** (I²C GPIO expander) in parallel with the manual reverse button (wired-OR via the motor controller's existing pull-up; the PCF8574's quasi-bidirectional outputs are natively open-drain). This frees GPIO 36, which the fitted N16R8's octal PSRAM consumes (decision 2026-05-03). The MAX4660's SELECT pin is driven by `SELECT_THROTTLE` on GPIO 15 with a 10 kΩ pulldown to GND, so the **hardware default is manual passthrough** whenever the ESP32 is crashed, hung, resetting, or unbooted. **Steering is NOT muxed** — the ESP32 always drives the Cytron H-bridge directly; in manual mode firmware sets PWM = 0. **This means steering has no hardware safe state, unlike throttle and the compressor.** `CMD_STEER_PWM` carries no pull resistor, so it is undriven whenever the ESP32 is unbooted, resetting, crashed or removed — the entire bootloader window of every flash — while the Cytron stays powered from the 48 V pack. On 2026-08-08 the steering swung to full lock during a reflash and broke teeth off the steering gears. Until a pulldown is fitted (dv-hardware `projects/kart-medulla/requirements.md` REQ-08), de-power the Cytron or unplug the steering motor before flashing.
- **Cytron H-bridge (steering driver) power (decision 2026-05-01):** fed **permanently from the 48 V traction pack** — not from the 12 V rail, and NOT switched through the manual/autonomous mode switch. The MD25HV takes 7–58 V, so the pack is within spec. Permanent is the point: the Cytron's inrush capacitors were browning out the Orin every time the kart was switched into autonomous. The PCB only routes signals (`CMD_STEER_PWM`, `CMD_STEER_DIR`) to the Cytron, not power.
- **REVERSE-signal driver to the kart electronics box — `Q4`, a BSS123 (decision 2026-04-26, done):** the driver is a **BSS123 N-channel logic-level MOSFET** (SOT-23), designator **Q4**, and it is fitted on the manufactured board. It replaced a **PC357N1J000F optocoupler** because medulla GND and box GND are bonded through several paths anyway (USB ↔ Orin, signals ↔ Cytron, motor return ↔ battery), so the opto's isolation was moot — the MOSFET is cheaper, smaller, faster, and doesn't age. The optocoupler was never placed on a schematic sheet; it exists only as an unused library entry in the EasyEDA source. Drives the box's REVERSE wire (5 V via ~60 kΩ internal pull-up; pull to 0 V to engage reverse). **Note:** older text called this part `U12`. There is no U12 on the board — the reference designators in the netlist are `U1, U02, U5, U13, U14, U19, U23, U24, U25`, and dv-hardware's pinout doc separately flags U12 as redundant. Use `Q4`.
- **Pressure sensor inputs (3× Festo, 24 V):** voltage divider + input clamp / TVS protection on each channel to bring the signal into the S3's ADC range (≤ 3.3 V).
- **Hydraulic pressure sensor inputs (2×):** routed to ADC1_CH9 (GPIO 10) and ADC1_CH1 (GPIO 2).
- **Hall sensor inputs (3× 5 V):** dedicated level translator (NOT the optocoupler) to 3.3 V before the GPIO pins.
- **Orin link:** UART0 over the DevKitC-1's on-board WCH CH343 bridge (the `COM` USB-C port), 115200 baud, appearing on the Orin as `/dev/ttyACM0`. The PCB adds no bridge chip of its own. GPIO 19/20 (D∓) go to the module's native USB port, which is wired but unused — switching the Orin onto it would move the serial console too, so it is not a drop-in change.
- **Power architecture:** kart 12 V → external XW-1224 buck → 5 V kart-wide rail → medulla 5 V (H1.21) → ESP32-S3 module LDO → 3.3 V. The medulla can alternatively be powered from an on-board LM2596SX-ADJ buck (qty 8 in stock) if the kart-wide 5 V rail is unavailable. MCP4922 VDD and MAX4660 Vcc both run from the same 5 V rail.

### Connector Pinout (Outside World)

The fabricated ESP32-S3 interface PCB brings every outside-world signal to ten 3-pin green push-in headers, **CN1–CN10** (per the board's `F.Silkscreen` layer).

**What is on each terminal: [Connector Pinout (CN1–CN10)](pinout.md).** That page carries the per-connector assignment table, the silkscreen block, the physical pin-order rules, and the two naming traps (`BUZZ` on CN8.2 is not a buzzer; `EXP_P2` is CN3.2). It is generated from the schematic-side file in `dv-hardware` — see the banner at the top of it.

**Which wire runs where: the [whole-kart wire list](../wiring.md#wire-list-whole-kart).** One row per net; search the `Connected pins` column for `medulla.CNx.y`. **Which GPIO a terminal reaches:** `projects/kart-medulla/docs/pinout-esp32-s3.md` in `dv-hardware`. Signal names follow the [Net Name Nomenclature](../net-naming.md) convention.

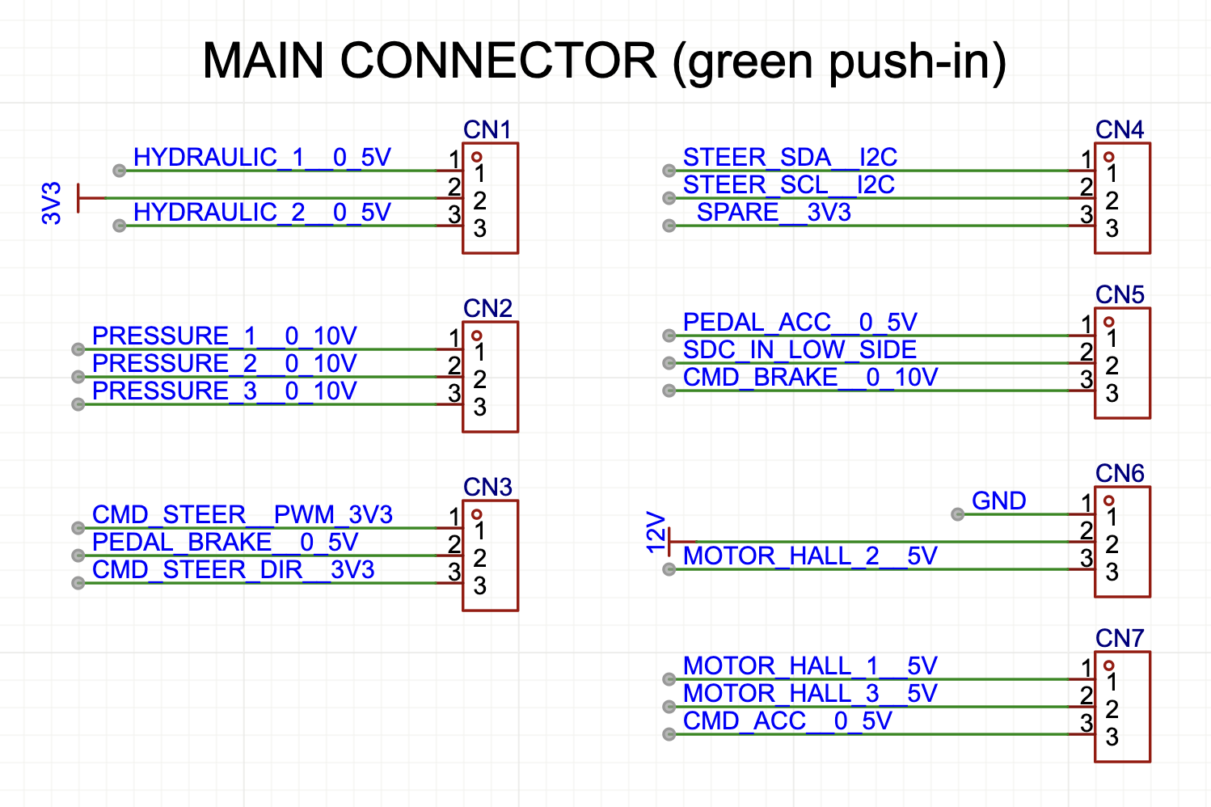
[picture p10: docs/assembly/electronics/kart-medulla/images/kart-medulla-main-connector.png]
Kart Medulla main connector (green push-in)


Terminal notes that aren't obvious from the wire list:

- **CN1–CN10 are 3-pin.** Supplies sit on CN1 (+3V3 / +12V / GND), CN2.3 (+5V), CN6.3 (+3V3), CN9.3 and CN10.3 (GND).
- **EXP_P1..P4** (CN3.1–3, CN5.3) are port pins of the on-board **U25 PCF8574** I²C GPIO expander (address 0x20) brought out to terminals — for example `CMD_REVERSE` lives on PCF8574 P0, not on a native GPIO.
- **CN4.3 REV** is the reverse-command wire to the kart electronics box (driven by `Q4`, the BSS123; 5 V idle via the box's internal pull-up, pulled to 0 V to engage reverse). CN4 carries **no 3V3/GND**.
- **CN5.2** (ex-PRES3) and **CN8.2** (ex-BUZZ) are the two repurposed terminals — steering-angle PWM and EBS-compressor PWM respectively (see the callout under the pin table).
- **CN8.1 SDC** is `SDC_IN_LOW_SIDE`, the Q3 drain that closes the kart shutdown chain's return path. The ESP32 side of that MOSFET (`SDC_NOT_EMERGENCY`, GPIO 18) is internal and deliberately not on any terminal.
- **CN10** analog commands come from the MCP4922 SPI DAC (the S3 has no native DAC).

!!! warning "Physical pin order runs opposite on the two sides"
    Pin 1 is **at the top** on CN1–CN5 (right side, footprint rotation −90°) and **at the bottom** on CN6–CN10 (left side, +90°) — verified against `kart-medulla.kicad_pcb` on 2026-07-10, superseding an earlier "1/2/3 top to bottom" reading that only held on the right. Because the CNs themselves advance bottom→top on the right and top→bottom on the left, pin numbering runs *counter* to connector numbering on both sides. Details and the staggered-footprint consequence are on the [Connector Pinout](pinout.md) page.

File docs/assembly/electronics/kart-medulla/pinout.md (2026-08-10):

<!-- sync_pinout source-sha256: 6edbe79727ad71578f9ef2a5ec249d2aaae38d0cb6f04686c4482914842b524a -->
<!-- sync_pinout source-commit: e4a6e109c3efa613601a6cc6cac4784cd8e1b7db -->
!!! info "Generated page — edit it in `dv-hardware`, not here"
    This is a verbatim copy of [`projects/kart-medulla/docs/pinout-cn-connectors.md`](https://github.com/UM-Driverless/dv-hardware/blob/e4a6e109c3efa613601a6cc6cac4784cd8e1b7db/projects/kart-medulla/docs/pinout-cn-connectors.md) in the **dv-hardware**
    repo, which holds the KiCad schematic that defines these assignments. Changes
    made here are overwritten. To update: edit the file in dv-hardware, then run
    `uv run python scripts/sync_pinout.py` in kart-docs and commit the result.

    Pinned to dv-hardware commit [`e4a6e109c3ef`](https://github.com/UM-Driverless/dv-hardware/commit/e4a6e109c3efa613601a6cc6cac4784cd8e1b7db) (2026-08-10). The link above is a permalink to that exact revision, so it keeps meaning what it meant when this copy was made; dv-hardware may have newer commits.

    Related: [Kart Medulla board](index.md) · [whole-kart wire list](../wiring.md#wire-list-whole-kart)
    · ESP32-S3 GPIO map in dv-hardware's `pinout-esp32-s3.md`.

# Push-in connector pinout (CN1–CN10)

> **Authoritative source: the schematic in this same project folder (`../kart-medulla.kicad_sch` + `../kart-medulla_P1.kicad_sch`).** This document mirrors the per-CN pin assignments for human reading. When this doc and the schematic disagree, the schematic wins; fix this file. Re-verify before each fab release.

The medulla PCB has 10 three-pin push-in (1990012) connectors arranged around the ESP32-S3 dev module. Each CN is a 3-pin Wago-style cage-clamp terminal; wires terminate independently per pin (no per-CN cable grouping is required — see `history.md` 2026-05-08 for context).

Connectors are placed in a "chip-pinout" layout to minimize jumper-wire length to the ESP32 module:

  - CN1–CN5 sit on the **right** side of the PCB, **bottom→top** (CN1 closest to USB, CN5 closest to the top edge). They map onto ESP32 pins 1–22 (right edge, RIGHT_HEADER).
  - CN6–CN10 sit on the **left** side, **top→bottom** (CN6 closest to the top edge, CN10 closest to USB). They map onto ESP32 pins 23–44 (left edge, LEFT_HEADER).

Pin numbering within each CN (verified against `kart-medulla.kicad_pcb`, 2026-07-10 — this
used to read "pin 1/2/3 from top to bottom", which is only true of the right-hand side):

  - **CN1–CN5** (right, footprint rotation −90°): pin **1 at top**, pin 3 at bottom.
  - **CN6–CN10** (left, footprint rotation +90°): pin **1 at bottom**, pin 3 at top.

Note the consequence: on the right the CNs advance bottom→top while their pins advance
top→bottom; on the left the CNs advance top→bottom while their pins advance bottom→top. So on
**both** sides the pin numbering runs *counter* to the CN numbering, and on both sides the wire
entry faces **inward**, toward the middle of the board. See the "flip the connectors" task in
`../tasks.md`.

Footprint is `CONN-TH_3P-P2.50-S5.00_1990012`: 2.50 mm pitch, and the pads are **staggered** —
pins 1 and 3 in one row, pin 2 in a row 5.00 mm across. A 180° rotation therefore moves pin 2's
pad row to the opposite side and is not a free change; the copper under each connector must be
re-routed.

## Silkscreen is the authority (v1, the only board that exists)

The table below is transcribed from the **v1 PCB silkscreen** — v1 is the only revision built, so
this is what is physically in front of you:

```
CN1        CN2        CN3        CN4       CN5        CN6        CN7        CN8         CN9          CN10
1 +3V3     1 HALL3    1 EXP_P1   1 SCL     1 HYD2     1 PED_BRK  1 PRES1    1 SDC       1 STEER_PWM  1 CMD_ACC
2 +12V     2 HALL2    2 EXP_P2   2 SDA     2 PRES3    2 PED_ACC  2 PRES2    2 BUZZ      2 HYD1       2 CMD_BRK
3 GND      3 +5V      3 EXP_P3   3 REV     3 EXP_P4   3 +3V3     3 HALL1    3 STEER_DIR 3 GND        3 GND
```

**Two naming traps, both of which have already caused confusion:**

1. **`BUZZ` on CN8.2 is an OLD name.** There is no buzzer on it. The net was repurposed to
   `CMD_COMPRESSOR_PWM` — GPIO 3 driving the EBS compressor MOSFET gate. Wherever `BUZZER` appears
   in this repo it should be read as *(old name)*. Note this collides with the rules-mandated ASSI
   buzzer, which still needs a home — see `projects/kart-medulla/tasks.md`.
2. **`EXP_P2` is CN3.2, and always has been.** A stale export of `projects/kart-medulla/output/netlist.net`
   (dated 7 May, re-exported 2026-08-10 and now current with the schematic) used to list
   `CN8.2 → /EXP_P2` and show Q3's and Q4's gates on no net at all — both artifacts of the schematic
   having moved on without a re-export. Re-exporting fixed both; the netlist now agrees with the
   silkscreen and this table. If a future edit makes them disagree again, trust the silkscreen and
   this table until the netlist is re-exported.
3. **Designator mismatch: schematic vs the fabricated v1 board.** An earlier draft of the schematic
   (before the netlist above was current) put the pressure channels on `CN2.1`/`CN2.2`/`CN2.3`. On
   the v1 silkscreen and PCB — the only board that physically exists — those pins are
   `CN7.1`/`CN7.2`/`CN5.2`, and PCB `CN2` is instead `HALL3`/`HALL2`/`+5V_REG` (see the assignment
   table below). **Anyone wiring the kart should read from the silkscreen/PCB, never from a
   schematic printout**, in case a future schematic edit drifts from the fabricated board again
   before a new revision is built.

## Assignment table

| CN | Side | Pin 1 | Pin 2 | Pin 3 | Function |
|---|---|---|---|---|---|
| **CN1**  | R, bottom | +3V3 | +12V | GND | **Power input + 3V3 export.** Pin 1 exports the ESP32-derived +3V3 rail (carries PWR_FLAG). Pin 2 = +12V from kart battery. Pin 3 = GND return. |
| **CN2**  | R | MOTOR_HALL_3 (5V) | MOTOR_HALL_2 (5V) | +5V_REG | Motor hall sensors 2 & 3. Pin 3 supplies +5V from the on-board rail to the hall sensor IC. |
| **CN3**  | R | EXP_P1 | EXP_P2 | EXP_P3 | Three PCF8574 expander GPIOs clustered next to U25 (PCF8574 placed on the right side of the PCB near CN3 — see `history.md` 2026-05-08 for the cluster decision). |
| **CN4**  | R | SCL (I²C, 3V3) | SDA (I²C, 3V3) | REVERSE_WIRE | Pins 1 & 2 = I²C bus to the AS5600 steering encoder *and* to U25 (PCF8574); U25 is the only on-PCB I²C device, AS5600 lives off-board on the steering shaft. Pin 3 = REVERSE_WIRE (PCF8574 P0 open-drain output to kart's REVERSE line, wired-OR with manual reverse button on the motor-controller side). |
| **CN5**  | R, top | HYDRAULIC_2 (0–5V) | CMD_STEER_PWM_IN (ex-PRESSURE_3) | EXP_P4 | Hydraulic-2 pressure sensor + steering-angle PWM input + spare PCF8574 expander GPIO P4. **Pin 2 is silkscreened `PRES3` but is NOT a pressure sensor** — no pressure sensor is fitted there; GPIO 1 was repurposed 2026-07-31 to read the MT6701 steering-angle sensor's PWM output via MCPWM capture. See "As-built pin use — board `84d6dd0`" in `pinout-esp32-s3.md`. |
| **CN6**  | L, top | PEDAL_BRAKE (0–5V) | PEDAL_ACC (0–5V) | +3V3 | Both pedal-position signals + 3V3 power output to whichever sensor needs it. (Carries PWR_FLAG on +3V3.) |
| **CN7**  | L | PRESSURE_1 (0–10V) | PRESSURE_2 (0–10V) | MOTOR_HALL_1 (5V) | Pressure-1 & Pressure-2 sensors + Motor hall 1. (Halls span CN2 + CN7 because GPIO 16 sits on the left side of the ESP32; see `history.md` 2026-05-08 for why no swap.) |
| **CN8**  | L | SDC_IN_LOW_SIDE | `BUZZ` **(old name)** = CMD_COMPRESSOR_PWM (3V3) | CMD_STEER_DIR (3V3) | Pin 1 = SDC chain return (Q3 drain). **Pin 2 is silkscreened `BUZZ` but is NOT a buzzer** — the net was repurposed to drive the EBS compressor MOSFET's gate (GPIO 3). It carries a 3.3 V logic signal, not power: the compressor MOSFET is external, added after the board was built, and this pin feeds its gate resistor. Pin 3 = Cytron H-bridge direction. |
| **CN9**  | L | CMD_STEER_PWM (3V3) | HYDRAULIC_1 (0–5V) | GND | Pin 1 = Cytron H-bridge PWM. Pin 2 = Hydraulic-1 sensor. Pin 3 = GND return for the left-side analog/SDC group. |
| **CN10** | L, bottom | CMD_ACC (0–5V) | CMD_PRES (0–10V) | GND | Pin 1 = throttle command, to the motor controller: MCP4922 VOUTA (0–3.3 V) goes through the LM358 U1B non-inverting stage (gain 1.51, set by R37 5.1K / R38 10K, giving 4.99 V full scale) straight to CN10.1. Nothing is muxed on this path — the MAX4660 (U14) that used to sit here has been deleted from the schematic; the panel DPDT switch on the kart, downstream of this board, is what selects whether the motor controller listens to this command or to the driver's pedal. Pin 2 = **pressure command to the Festo VPPM proportional regulator, not to the motor controller** — braking on this kart is pneumatic. It is VOUTB amplified ×3 by the LM358 (U1A) (R19 = 2K, R20 = 1K), so 9.9 V leaves the board, not 10 V exactly, since the DAC's full scale is 3.3 V rather than 5 V — the MCP4922 U13 was moved from +5V to +3V3 on 2026-08-01 (commit 16a35fb) to fix an SPI logic-threshold problem. The net was called `CMD_BRAKE` until 2026-07-31; it is `CMD_PRES__0_10V` now, because the signal is a pressure setpoint for a proportional regulator rather than a brake-force command. The silkscreen on the built board still reads `CMD_BRK`. Pin 3 = GND, and it is also the **return the VPPM's setpoint is measured against**: the valve runs from a separate 24 V supply, so that supply's 0 V must be common with the medulla's GND or the commanded pressure shifts by whatever the offset is. |

## The pneumatic side — three devices, three supplies, only one of them on a medulla pin

Written 2026-07-31 because "the valve" was being used to mean different things. Sources:
`~/dv/kart/pneumatics/README.md` and `~/dv/kart/pneumatics/history.md` (2026-05-30).

| Device | Festo part | Its own supply | What the medulla does |
|---|---|---|---|
| **VPPM-8L proportional pressure regulator** | 571293 | **24 V DC** (21.6–26.4 V, 300 mA, 7 W) from a UENPO 9–36 V → 24 V buck-boost | Drives its **0–10 V setpoint** out of **CN10.2** (`CMD_PRES__0_10V`). GND on **CN10.3** is the return that setpoint is measured against. The medulla does **not** supply its 24 V. |
| **EBS emergency electrovalve** (and the ASB valve) | 8035174 / 8035167, VUVS-LT25 | **12 V** coils, switched by the **shutdown relay** | Nothing. No medulla pin touches it. |
| **SDE5 pressure sensors** | 567465 | 15–30 V, fed from the same 24 V rail | Reads their **0–10 V outputs** on `PRESSURE_1`/`PRESSURE_2` (CN7.1, CN7.2) through dividers |

The setpoint and the supply are different things on the VPPM: 0–10 V is the command, 24 V is what
powers the valve. When a note here says a 24 V fault could reach a medulla pin, it means the VPPM's
supply appearing on CN10.2 through a harness fault — not the EBS valve, which is 12 V and not wired
to this board at all.

The VPPM setpoint is a signal input and the LM358 drives it directly; its input impedance was
treated as an open question until 2026-07-31 and is not one.
## Voltage levels — quick reference

| Suffix in signal name | Meaning |
|---|---|
| `__3V3` | 3.3 V logic level (ESP32 native) |
| `__5V` | 5 V logic level (motor hall, level-shifted by U5 to 3V3 before reaching the ESP32) |
| `__0_5V` | analog 0–5 V (sensors, DAC outputs) |
| `__0_10V` | analog 0–10 V (pressure sensors) |
| no suffix on power names (`+12V`, `+3V3`, `+5V_REG`) | rail of that nominal voltage |

`SDC_IN_LOW_SIDE` is the drain of Q3 (IRLZ44N): nominally 0 V when Q3 conducts (no emergency), floats up to whatever the upstream SDC node sits at (≤ 12 V) when Q3 is off (emergency). Treat it as a 12-V-tolerant line.

## Power architecture summary (where each rail comes from)

  - `+12V`         — externally, from the kart battery, via **CN1 pin 2**.
  - `+5V_REG`      — on-board L7805CDT linear regulator (U19), or the external XW-1224 5 V rail tied in via the same net, feeds the `+5V_REG` global net.
  - `+3V3`         — generated by the ESP32-S3 module's on-board LDO from its 5 V input. Available on LEFT_HEADER pins 23/24 of the dev module.
  - `+5V_USB`      — independent 5 V rail from the medulla USB-C connector; powers only the ESP32 dev module (split-rail design, see `pinout-esp32-s3.md`).

The single `power:+12V` symbol that asserts the `+12V` rail name is placed at CN1 pin 2 (the entry point). Same convention applies to `+3V3` and `+5V_REG` symbols on whichever CN exports them — the symbol just declares the rail and can sit anywhere on the net.

## Cross-reference

  - ESP32 module pinout → `pinout-esp32-s3.md` (which GPIO drives which signal in the table above).
  - PCB physical layout / silkscreen → the `kart-medulla.kicad_pcb` file in this folder. The silkscreen legend that lists the 21 numbered external signals is being updated to match this assignment.
  - Decision history → `../../../history.md` entry `2026-05-08 — kart-medulla CN1–CN10 pin assignments locked to ESP32 geometry`.

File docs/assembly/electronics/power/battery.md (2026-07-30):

# Battery

> To charge the battery with a bench power supply, see this tutorial: [Cómo Cargar una Batería de Litio con una Fuente](https://youtu.be/g1jsSbjsiTo?si=uZ7mVjXA2c-43zzz)

The main pack uses **Molicel P42A** cells in a 13S4P configuration, providing a nominal voltage of about 48 V. The 12 V rail that powers the sensors and low-voltage electronics is stepped down from the pack by the DC-DC converter below; this replaced the separate 12 V battery the kart used earlier to stay compatible with the Formula Student car.

For battery placement rationale see the [FAQ](../../../faq.md#battery).

| Parameter | Value |
|---|---|
| BMS Cutoff voltage | 39.0 V (13 * 3.0V) |
| Configuration | 13S4P (13 cells in series, 4 in parallel) |
| Nominal voltage | 46.8 V (13 * 3.6 V) — standard 48 V system label |
| Maximum charging voltage | 54.6 V (13 * 4.2V) |
| Minimum voltage | 41.6 V (13 * 3.2V) |
| Power Capacity | 786 Wh (3.6V * 4.2 Ah * 13 * 4) |
| Charge capacity | 16.8 Ah (4 * 4200 mAh) |
| Maximum continuous discharge current | 180 A (4 * 45 A. 9828W at 100% charge!!) |
| Maximum continuous charge current | 32 A (4 * 8 A. about 1.7kW) |
| Cell type | Molicel P42A |
| Cell capacity | 4200 mAh (4.2 Ah) |
| Cell nominal voltage | 3.6 V (per Molicel INR-21700-P42A datasheet) |
| Cell maximum voltage | 4.2 V |
| Cell minimum voltage | 3.2 V |

## 48 V → 12 V converter

The 12 V rail is generated from the 48 V traction pack by a **Weishuo Y3-T4812** step-down (buck) DC-DC converter. There is no separate 12 V battery — this converter replaced the previous 12 V lead-acid aux battery (see the [full BOM](../../../bom/full.md)). Everything on 12 V hangs off it: the pneumatic Festo pressure sensors (via a 12 → 24 V boost) and the downstream 12 → 5 V / 3.3 V bucks. The steering H-bridge is **not** on this rail — the Cytron is fed straight from the 48 V pack.

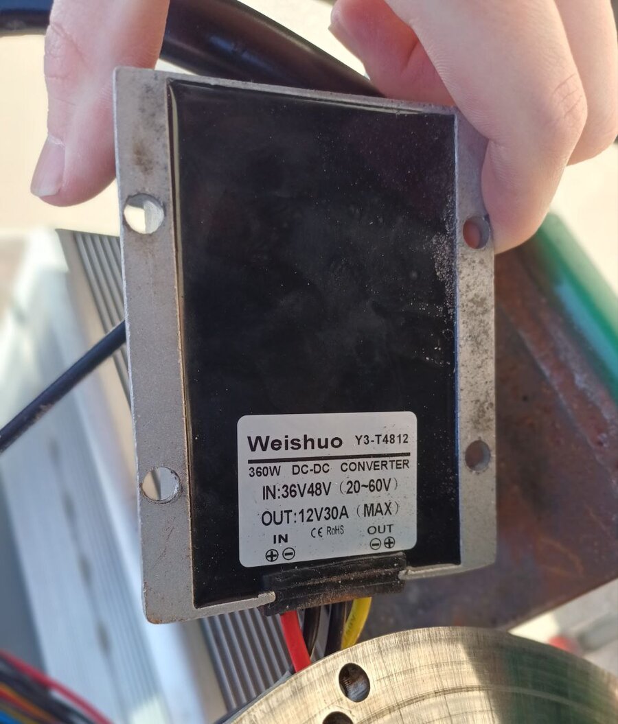
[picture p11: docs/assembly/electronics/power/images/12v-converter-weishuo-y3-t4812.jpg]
Weishuo Y3-T4812 48 V → 12 V DC-DC converter


| Parameter | Value |
|---|---|
| Model | Weishuo Y3-T4812 |
| Type | Step-down (buck) DC-DC converter |
| Rated power | 360 W |
| Input voltage | 36 V / 48 V nominal (20–60 V range) |
| Output voltage | 12 V |
| Output current | 30 A max |
| Terminal polarity | IN ⊕⊖, OUT ⊖⊕ (marked on the label) |

The 13S4P pack operates at roughly 41.6–54.6 V, well inside the converter's 20–60 V input window.

## BMS
- Jiabaida BMS, 100A BT UART, NMC 6S-21S
- https://www.notion.so/BMS-Bater-a-Kart-JBD-16078747314380e68688c3ab787fc1f7?pvs=21
- https://es.aliexpress.com/item/1005007223779359.html
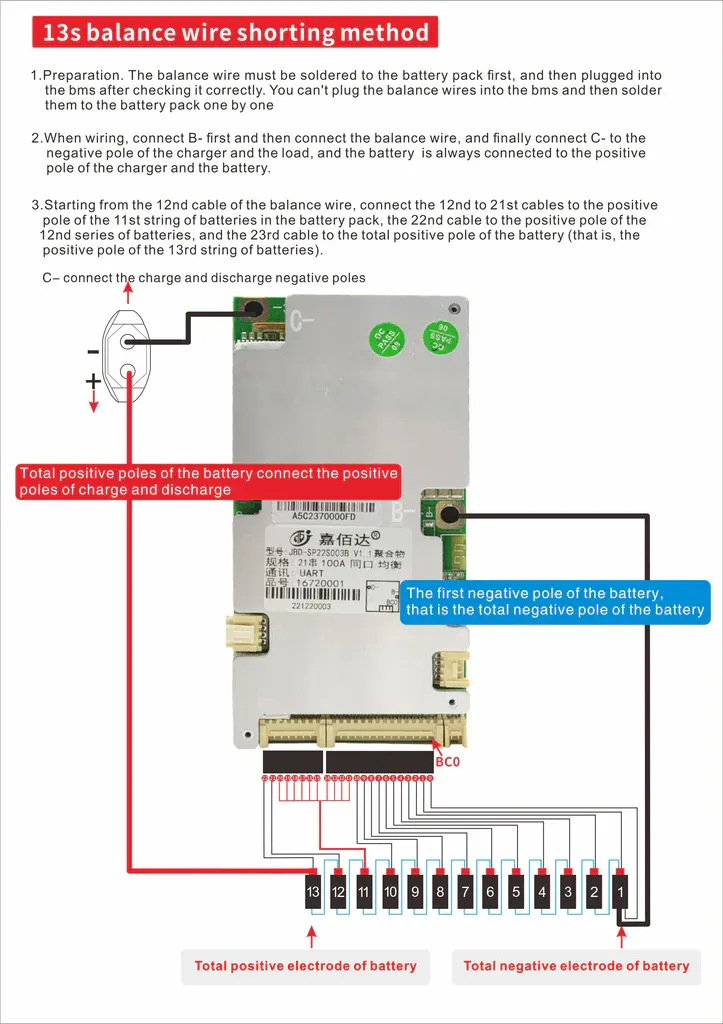
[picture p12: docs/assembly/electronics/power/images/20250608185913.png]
https://jiabaida-bms.com/blogs/content/jiabaida-sp22s003b-smart-bms-wiring-diagram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


!!! note "Software: reading the BMS"
    The Jetson Orin reads this BMS over **Bluetooth LE** (no ESP32, no CAN) and publishes it as a ROS `BatteryState` topic that drives the dashboard battery gauge. See the [BMS (battery node)](../../../software/ros2/bms.md) software page for the `kb_bms` node and the JBD BLE protocol.

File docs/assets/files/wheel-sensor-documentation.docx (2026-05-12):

# SENSORIZATION (SEN)

Sensorization se encarga de recoger información de las ruedas y transmitirlas por CAN al resto del coche.

# Hardware

## Components

Reluctors (Transductor de reluctancia variable):

New small to use, choose from these:

MP37TA00 - 46€ - M12 x 32mm largo

https://es.rs-online.com/web/p/sensores-de-control-de-movimiento/9055298/

RS-PRO 304-166 - 51€ - 6.25 diam x 22 mm largo

https://es.rs-online.com/web/p/sensores-de-control-de-movimiento/0304166/

3015A – 100€ - 2.36 diam mayor x 20 mm largo – 28g

https://es.rs-online.com/web/p/sensores-de-control-de-movimiento/2132725/

Big, in reserve: TM-HAADA

Datasheet: https://www.mouser.es/datasheet/2/187/Honeywell_TM_Series_DSL-1168391.pdf,

https://www.mouser.es/ProductDetail/Honeywell/TM-HAADA

M18 thread, GX16 connector

Small, to use: 3030AN M16

M16 thread, MS3106 connector.

Datasheet: https://www.mouser.es/datasheet/2/187/005876-1-EN-1846189.pdf

https://www.mouser.es/ProductDetail/Honeywell/3030AN?qs=fnYUjNMxfVAJAJ3FIK76Kg%3D%3D

https://es.rs-online.com/web/p/sensores-de-control-de-movimiento/8228398

Search:

https://es.rs-online.com/web/c/automatizacion-y-control-de-procesos/sensores-industriales/sensores-de-control-de-movimiento/

## Cabling

From up right to up left – 1 to 6

From low right to low left – 7 to 12

Pin1 – 5V connection from buck.

Pin2 – Rel -, ORANGE CABLE

Pin3 – Rel +, BROWN CABLE

Pin4 – Analog input 2

Pin5 – Analog input 1

Pin6 – Analog input 0

Pin7 – GND - CABLE BROWN-BLUE thicker.

Pin8 - Digital input 0

Pin9 - Digital input 1

Pin10 – CANH – GREEN CABLE

Pin11 – CANL – BLUE CABLE

Pin12 – 12V_IN – brown cable

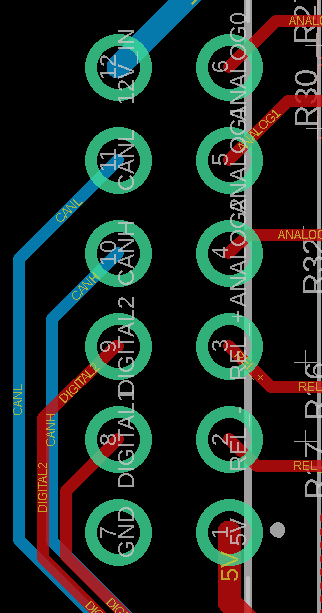
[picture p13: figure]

## Tacómetro – Sensor movimiento ruedas

Incluye un sensor de movimiento basado en una rueda fónica con un reluctor, que incluye un imán y una bobina, de manera que cuando se acerca un material ferromagnético (acero), como los dientes de la rueda fónica, genera una onda sinusoidal cuya frecuencia e intensidad varía con la velocidad del coche. Es un sensor muy fiable, resiste el calor y la suciedad, y no requiere contacto ni alimentación, pero a bajas velocidades no puede detectar el movimiento de las ruedas ya que la señal tiene una intensidad proporcional a la velocidad. Es como un transformador con frecuencias muy bajas. La transformación de la señal sinusoidal en una digital se realiza en la pcb de SEN con un MAX9924 (MAX9926) o LM1815. También hay reluctores que la llevan incorporada, con 3 cables (V+, GND, SIGNAL).

La alternativa sería un sensor Hall, más sencillo de utilizar al generar una señal digital, y que siempre detecta la presencia del diente, pero más sensible a la separación entre sensor y rueda fónica, interferencia electromagnética, temperatura, y que requiere alimentación, filtrado de la señal (parpadeos rápidos etc), y suelen ser más caros.

El microcontrolador PIC18 (F26K83) se encarga de contar las señales digitales resultantes, que generan interrupciones, y calcula la frecuencia y velocidad.

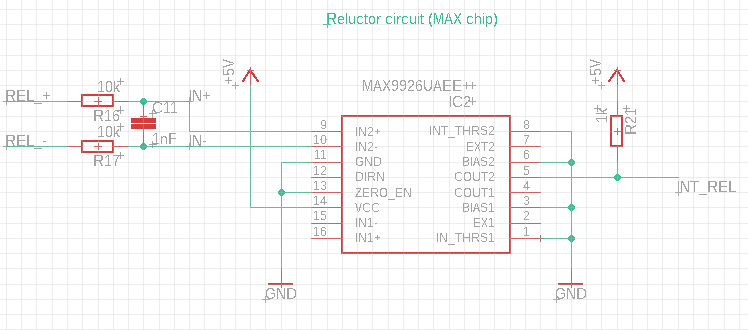
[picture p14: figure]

## IMU – Inertial Measurement Unit

El IMU mide la aceleración, rotación, y el campo magnético en la placa en 3 ejes. En total serían 9 valores. Se conecta con el microcontrolador, que ya se encarga de gestionar los datos y pasarlos a CAN. Como el micro funciona a 5V y el IMU a 3.3V es necesario el “level shifter”, que transmite señales en ambas direcciones cambiando su voltaje.

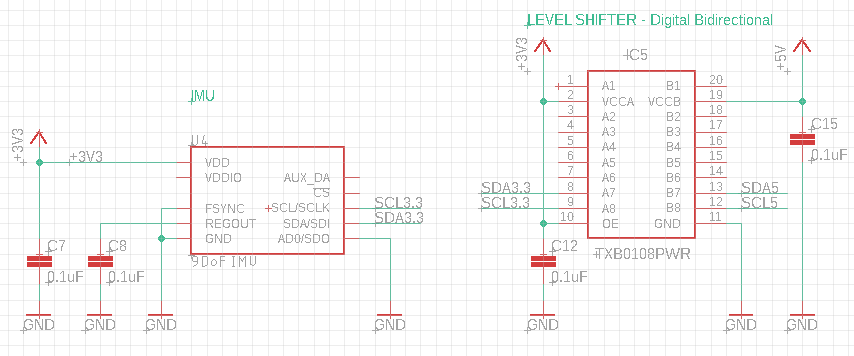
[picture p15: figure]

## Alimentación

Para la alimentación se ha utilizado un convertidor Buck de 12V a 5V, estándar en varias placas del coche, pero se piensa reducir su tamaño o utilizar un regulador lineal, porque la placa consume muy poca energía.

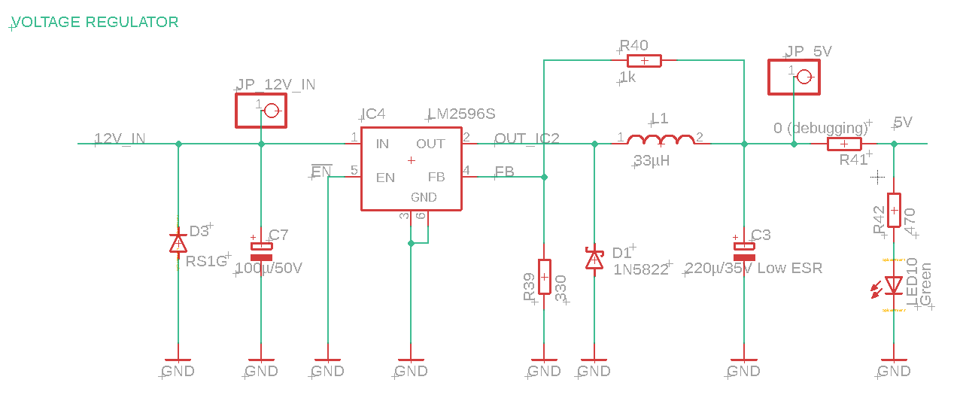
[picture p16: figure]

## CAN

El microcontrolador genera las señales digitales (5V) con los bits de CAN, y se utiliza un driver can, que genera los pares de señales con los voltajes correctos cumpliendo la especificación CAN.

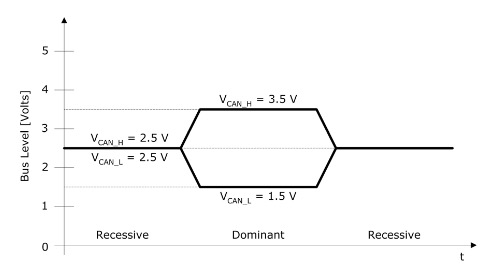
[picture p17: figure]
CAN Bus And SAE J1939 Bus Voltage - Copperhill
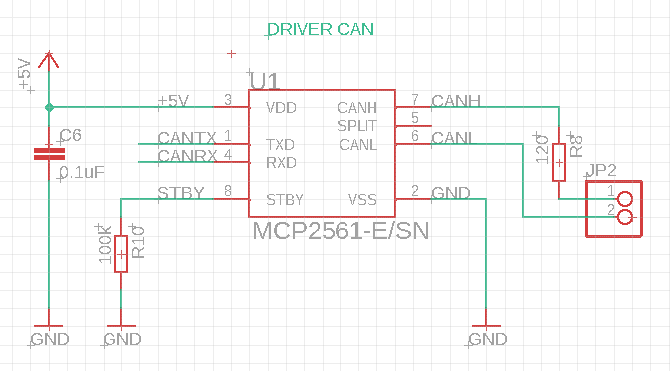
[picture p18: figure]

## Entradas digitales y analógicas

La placa también dispone de entradas para varios usos futuros. Las 2 entradas digitales están optoacopladas, y las 3 entradas analógicas simplemente tienen un filtro paso bajo y una resistencia para limitar la corriente, en serie. Las entradas digitales se conectan con entradas de interrupción del micro, y las analógicas a los convertidores de analógico a digital ADC. Dependiendo del voltaje de las señales se deben ajustar las resistencias. Por ejemplo: el optoacoplador soporta como máximo 50mA en la entrada, por lo que una señal de 5V necesita una resistencia de 100ohm en serie, como mínimo (realmente habría que tener en cuenta la caída en el diodo: R = (V-V_F)/I_max = (5-1.18)/50e-3 = 76.4ohm, pero al ignorarlo hay un margen de seguridad de 1.18V). Cuidado con aplicar la tensión en sentido inverso (max 6V en el VOS617AT (https://www.vishay.com/docs/83497/vos617a.pdf)).

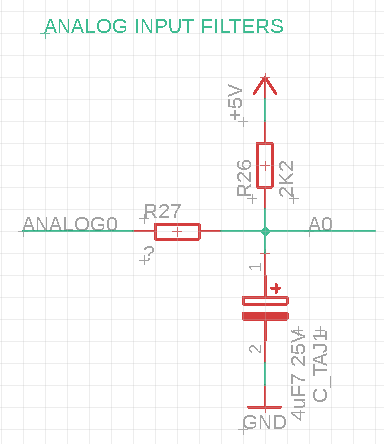
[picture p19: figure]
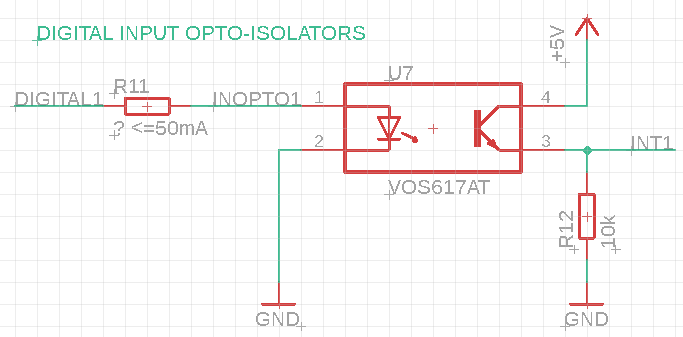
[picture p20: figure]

## Microcontrolador – PIC18F26 (K23, Q84)

Datasheet: https://ww1.microchip.com/downloads/en/DeviceDoc/39564c.pdf

El microcontrolador se programa con el programador Pickit 4 (https://www.mouser.es/ProductDetail/Seeed-Studio/114992143?qs=vHuUswq2%252Bsz2OBJI400dLA%3D%3D), el software MPLAB X IDE (https://www.microchip.com/en-us/development-tools-tools-and-software/mplab-x-ide) (v5.45 en 2021/10), utilizando el plugin MCC (https://www.microchip.com/en-us/development-tools-tools-and-software/embedded-software-center/mplab-code-configurator) (que añade una interfaz gráfica para configurar los PIC y autogenera el código) y el compilador XC8 (https://www.microchip.com/en-us/development-tools-tools-and-software/mplab-xc-compilers), en C.

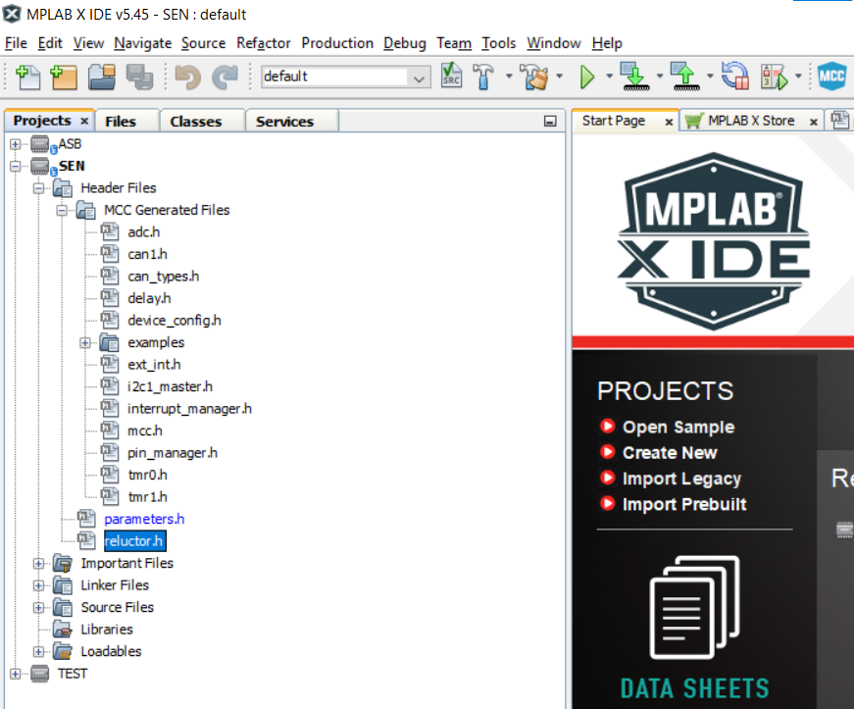
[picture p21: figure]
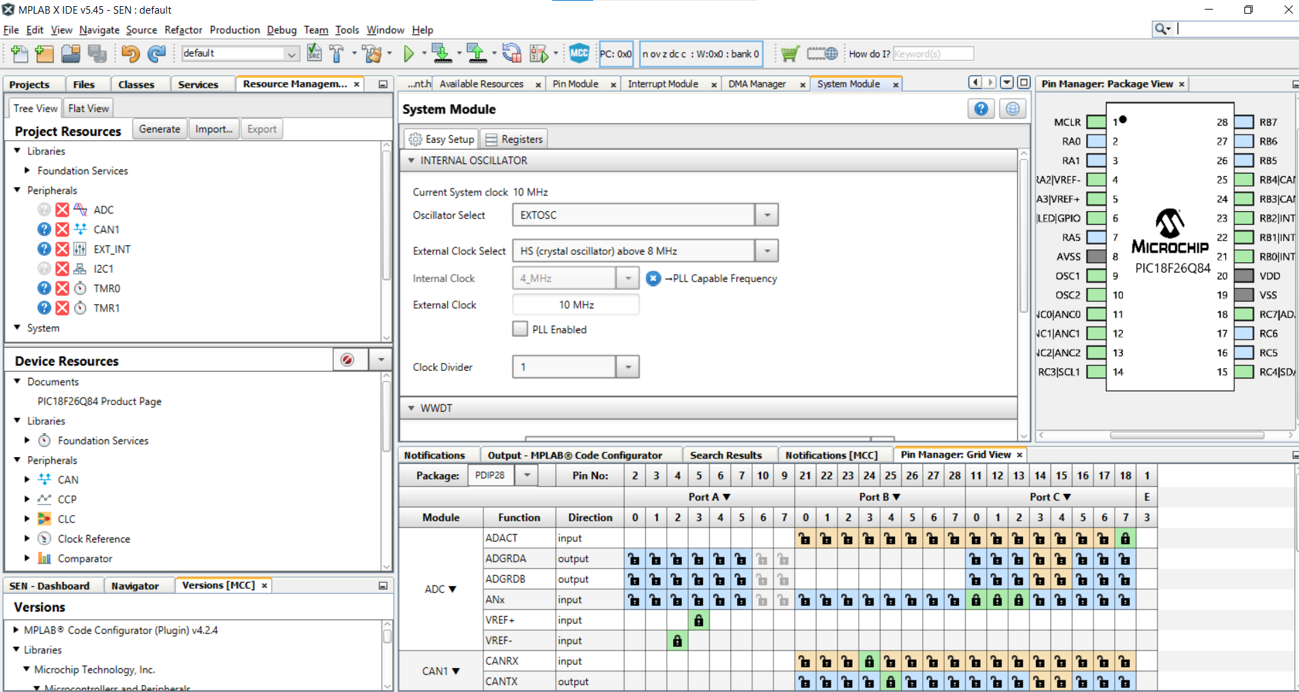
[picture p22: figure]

# Software

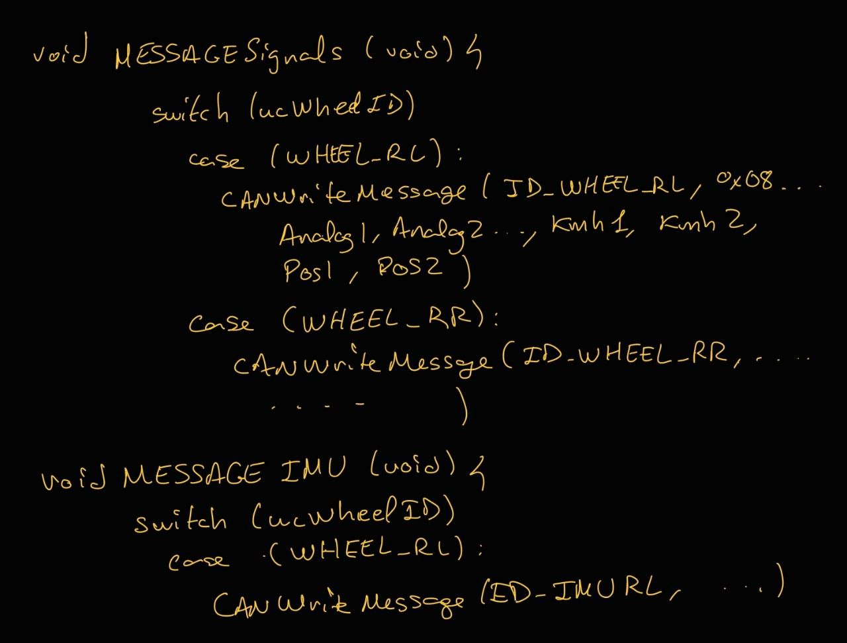
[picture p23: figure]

Interrupciones cada 10ms (TMR0) y 100ms (TMR1). Frecuenciómetro cada 100ms.

Ambas tienen callback de 5 veces. A veces se usa el callback para ejecutar funciones y a veces el timer directamente.

Usamos el mensaje de ERROR como heartbit de sen. Se envía cada 1-10 segundos para decir que todo ok o hay algún fallo. Si no se envía consideramos error.

La función CANWriteMessage se ejecuta cada 100ms de acuerdo al timer TMR1.

Falta solucionar timer correcto. El tiempo salía distinto.

Enviar vueltas y posición o directamente conteo de dientes?

Position error, 1 id con 8 bytes para errores.

Mensaje entrada que las ruedas tienen que leer, para resetear posición, valores imu, frecuencia, etc.

Ejecutar en el main principal e Inicializar las variables y la funcion messages.h y messages.c. código de función en .c. variables en ambas.

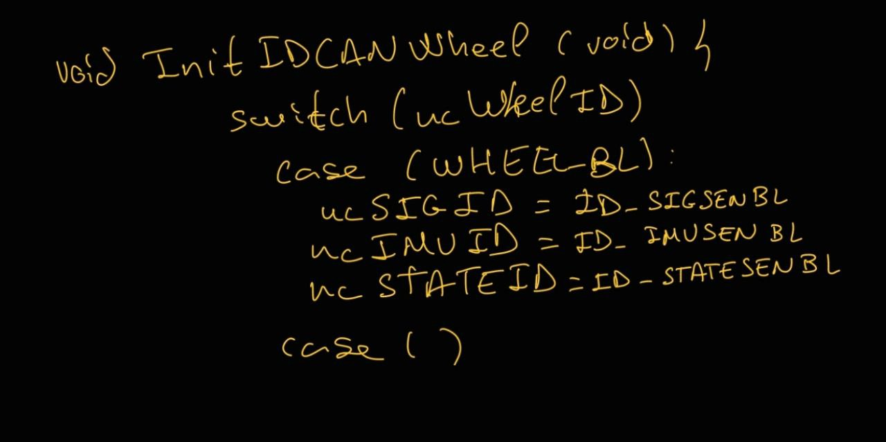
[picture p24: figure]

## Módulos

- CAN
- 2 entradas digitales GPIO
- 1 salida digital GPIO para LED.
- 3 entradas ADC
- I2C para el IMU (SDA SCL)
- Timers (interrupciones del chip que se ejecutan solas cada x tiempo). Para contar dientes reluctor.
- Interrupciones externas: reluctor y 2 entradas digitales optoacopladas.

## Mensajes CAN

Considerar BOSCH ABS M5 can para comunicar directamente con la Haltech.

4 ruedas con 4 id distintos.

Entradas: mensaje para tarar sensores, mensaje de configuración (cambiar frecuencia de envío, devuelve solo acc, modificar parameters etc..)

Salidas: Acelerómetro (3 bytes, 3 ejes), giroscopio (3 bytes, 3 ejes), velocidad ruedas del reluctor (0-120 km/h, 0-33.3m/s, 0-20Hz, 0-1200 rpm, en km/h ocupa 1 byte), Magnetómetro (2 ejes), Analog 0, Analog 1, Analog 2, Digital 1, Digital 2

1 id mensaje error

MENSAJE IMU (8 bytes): Accel (3) + Giroscopio (3) + Magnet (2)

ANALOG (3byte) + DIGITAL (1byte) + REL (1-4byte)

MENSAJES DE SALIDA QUE PROPORCIONA SEN:

MESSAGE | DATA[0] | DATA[1] | DATA[2] | DATA[3] | DATA[4] | DATA[5] | DATA[6] | DATA[7]
IMU | Accel x | Accel y | Accel z | Giro x | Giro y | Giro z | Mag x | Mag y
IO | Analog 1 | Analog 2 | Analog 3 | Digitals | Rel 1 | Rel 2 | Rel 3 | Rel 4
STATUS | Hearthb | Errors

# PCB

- SENv_00: con chip de reluctor LM1815 (https://www.ti.com/lit/ds/symlink/lm1815.pdf)
- SENv_01: con chip de reluctor MAX9924 (https://datasheets.maximintegrated.com/en/ds/MAX9924-MAX9927.pdf) (no encontramos)
- SENv_02: con chip de reluctor MAX9926 (https://datasheets.maximintegrated.com/en/ds/MAX9924-MAX9927.pdf). Igual que el MAX9924 pero doble. Más común
- SENv_03: SENv_02 con resistencia pullup que debería tener el max. Leds del regulador de tensión cambiados, reorganizado.
- SENv_04: Cambio en fuente de alimentación para reducir tamaño. Reguladores lineales. Cambiamos a empaquetado 0603? GND, 12V, 5V, y 3.3V tienen un header. Pequeñas mejoras. Queda comprobar si CAN está bien. Intentar poner conector en el medio. Se quita IMU y se añade amplificador para sensor temperatura de los neumáticos

## SEN_v02

A self-designed and manufactured circuit board placed on each wheel, with an IMU sensor, 3 analog inputs, 2 digital inputs, a tachometer (external reluctor sensor), and CAN transceivers to send all the data to the PMC. Uses a PIC18F26K83-I_SS programmable microcontroller, and takes 12VDC.


CHARACTERISTICS:

Size: 33.9852 x 50.673 mm.

Type: Plated holes. Substratum: Resin and glass fibres.

PROCESS:

1. Circuit schematic design.

2. Board implementation design.

3. Track and hole manufacture using specialized machine.

4. Hole soldering.

5. Component soldering.

6. Testing.

COMPONENTS:

Component | Specifications | QTY
MA05-1 | | 2
PINHD-1X1 | | 6
PINHD-1X2 | | 2
R-EU_M0805 | 0 | 4
R-EU_R0805 | 0 | 10
C-EUC0805 | 0.1uF | 20
C-EUC0805 | 0.33uF | 1
R-EU_R0805 | 1.6M | 1
R-EU_R0805 | 100k | 2
CPOL-EUG | 100Âµ/50V | 2
R-EU_M0805 | 10k | 4
R-EU_R0805 | 10k | 6
C-EUC0805 | 10uF | 2
R-EU_R0805 | 120 | 2
R-EU_R0805 | 150k | 1
CRYSTALS OSC | NOGND-HC49 - 1MHz | 2
DIODE | SCHOTTKY - 1N5822 | 2
R-EU_R0805 | 1k | 3
C-EUC0805 | 1nF | 2
CPOL-EUF | 220Âµ/35V Low ESR | 2
C-EUC0805 | 22pF | 4
R-EU_R0805 | 2K2 | 6
R-EU_R0805 | 310 | 4
Inductor | 33ÂµH | 2
R-EU_R0805 | 3k | 2
R-EU_R0805 | 470 | 4
R-EU_R0805 | 4k7 | 10
TAJA475K025RNJ | 4uF7 25V | 4
TAJA475K025RNJ | 4uF7 25V | 2
R-EU_R0805 | 7k | 1
ICM-20948 | 9DoF IMU | 2
LED_E | Green | 6
LM1815MX_NOPB | LM1815MX_NOPB | 1
LM2596S | LM2596S | 2
LM2937IMP-3.3 | LM2937IMP-3.3 | 2
MICROCHIP_MCP2561 | MICROCHIP_MCP2561-E-SNMICROCHIP_MCP2561-E-SN_0_0 | 2
MX23A12NF1 | MX23A12NF1 | 2
PINHD-1X2 | ON | 4
PIC18F26K83-I_SS | PIC18F26K83-I_SS | 2
DIODE-DO214AC | RS1G | 2
TXB0108PWR | TXB0108PWR | 2
VOS617AT | VOS617AT | 4

## SEN_v03


## SEN_v04

2/2 Universidad Rey Juan Carlos www.UMotorsport.es

Sensorization PCB specifications DV-PC-A0003

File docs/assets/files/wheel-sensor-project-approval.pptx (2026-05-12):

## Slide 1

PA – Project Approval

11/09/2020

Project cost estimation: 360€


Sensorization, odometry, and position


David Jiménez Urbano: Division chief

Jose Sebastián, Rubén Jiménez: Project manager

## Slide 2

Index

Sensorization, odometry, and position

- Concept
- Targets
- Validation Plan
- Deadlines: Design Release and Shipped
- Budget
- Affected documents

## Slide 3

Concept

Sensorization, odometry, and position

- Read the speed of all wheels, GPS, IMU data, and any future sensor.
- There are going to be 4 sensor boards, one per wheel, mainly for odometry.


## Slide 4

Concept

Sensorization, odometry, and position

- We have chosen reluctors (passive wheel speed sensors) instead of hall effect sensors, because of their lower price, the lower distortion of a sinusoid signal from a reluctor instead of a square wave from the hall-effect sensor, and the fact the it doesn’t need a power supply to work.

Hall effect | Reluctor
Noisy square wave signal | Sinusoidal wave signal. Not noisy once converted
Not sensitive to air gap | Sensitive to air gap
Sensitive to temperature | Not sensitive to temperature
Active sensor – 3 cables | Passive sensor – 2 cables
Common in normal cars | More reliable under vibrations
More expensive | Cheaper

- Also, we will need phonic wheels made from some magnetic steel (Or maybe just magnets). Ideally some Ferritic or Martensitic stainless steel like 440.

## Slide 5

Concept

Sensorization, odometry, and position

- The GPS and IMU sensors will be placed on the main PMC (PCI Mezzanine Card).
- The sensor boards will communicate through a CAN bus.

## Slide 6

Targets

Sensorization, odometry, and position

- Durability. If a sensor breaks under normal use, the design will have to be updated to prevent it.
- Ease of assembly and adjustment.
- Reliability
  - For wheel speed sensors: >= 99% of correct detection and <= 1% false positives (Over the amount of teeth that passed the sensor) at all reasonable temperatures and speeds.
  - Clear data from GPS and IMU. Low noise levels.
- Lower possible cost after meeting the previous targets. (About 150g per wheel + sensor according to the first designs)
- Lower possible weight after meeting the previous targets


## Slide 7

Validation Plan

Sensorization, odometry, and position

- Wheel speed sensors:
  - First visually check the sensor signal.
  - Check the teeth frequency after manually turning the wheel.
  - Turn the wheel at high speeds and then stop it at the same position it started with, while counting the tooth detections. The tooth count should be a multiple of the amount of teeth in the phonic wheel.
- GPS: Check detection speed, noise and consistency
- IMU: Should detect acceleration of 1g downwards

Lab test

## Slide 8

Validation Plan

Sensorization, odometry, and position

- Wheel speed sensors:
  - Check that the measured speed matches with GPS and calculations with tracks of known length.
  - Check the temperature and general condition of the sensor after prolonged use.
- GPS: Compare gathered data with the track map
- IMU: Check reasonable values.

Road test

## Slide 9

Deadlines: Design Release (DR) and Shipped

Sensorization, odometry, and position

- Preliminary concept
- Design Release
- Test breadboard
- Test PCBs
- Test on road
- Shipped

18/09/2020
10/10/2020
20/10/2020
20/11/2020
20/12/2020
10/02/2020

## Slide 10

Budget

Sensorization, odometry, and position

Item | Unitary Price | Quantity | Total
Wheel Speed Sensor | 27€ (mouser (https://www.mouser.com/catalog/specsheets/Honeywell_TM_Series_DSL.pdf)) | 8 (4 + spare parts) | 216€
Phonic wheels (laser cut) | 0 | 12 | 0
GPS | 10€ | 2 | 20€
IMU | 17€ | 2 | 34€
PCB | 5€ | 4 | 20€
Components | 70€ | 1 | 70€
TOTAL | | | 360€

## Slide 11

Affected documents

Sensorization, odometry, and position

Document | Name | ¿Affected?
SE3D | Structural equivalency 3D Model
IAD | Impact Attenuator Data
SES | Structural Equivalency Spreadsheet
SESA | Structural Equivalency Spreadsheet Approval
FTO | Fuel Type Order
CRD | Cost Report Documents
BOM + CBOM | Bill of Materials
CEF | Cost Explanation File (Part of CRD)
SM | Supporting Material (Part of CRD)
EDR | Engineering Design Report
DSS | Design Spec Sheet
BPES | Business Plan Executive Summary

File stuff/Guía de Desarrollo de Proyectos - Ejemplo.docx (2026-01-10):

# DOCUMENTACIÓN DEL PROYECTO


UNA DESCRIPCION DEL PROYECTO EN 1 LINEA

(Poned aquí el nombre de los responsables del proyecto)

# Descripción general

El proyecto consiste en… (un par de párrafos, resumen breve del proyecto, el detalle se da en los objetivos)

# Nomenclatura

ASB – Autonomous System Brake

EBS – Emergency Braking System

PMC – Principal Microcontroller

ETC – Electronic Throttle Control

ASF – Autonomous System Form

…

# DEFINICIÓN DE Los Objetivos y Problemas que soluciona

Similar o los mismos (si es que no cambiaron) a los que se exponen en el PA. Debes explicar cual es la necesidad por la que nace tu proyecto y que objetivos planteas conseguir (deben ser realistas para la duración del proyecto).

En el apartado de problemas, exponer de la siguiente manera:

PROBLEMA

Falta de precisión

SOLUCIÓN

Se añaden sensores extra y se modifican actuadores

PROBLEMA

Lo que sea….

SOLUCIÓN

Lo que sea…

# Definición de los requisitos y limitaciones de la normativa


Estos son los objetivos / requisitos mínimos e indispensables para lograr tus objetivos. Se divide el proyecto en subsistemas y se explican para cada uno. Pueden ser cosas como respuesta rápida (que sea menos de x), factores de seguridad, si hay interferencias con otras secciones y se establecen limites en los diseños, etc. Además, se deben tener en cuenta la normativa de la competición o incluso posibles restricciones nacionales.

Subsistemas

Requisitos

# Diagrama global del Proyecto

## Componentes


Muy simple, explicar para que se va a usar cada uno, no hace falta entrar mucho en detalles, estos son tanto fabricados por nosotros como comprados.

## DiagramaS

### Global

Una versión muy básica de lo que es el sistema. Como si se lo pintases a alguien para explicarle rápido en que consiste. Ej:


### INTERFAZ FÍSICA / SISTEMA ELECTRÓNICO (HARDWARE / CABLEADO / ALIMENTACIÓN

En este caso, el material que se debe incluir es:

- Diagramas de placas algo simple si es muy complejo, añadirlo al anexo. Ej:


- Diagramas de cableado (tanto de señales como de alimentación). Ej:


- Diagramas de las interconexiones incluyendo una explicación de los pinout. En concreto de los conectores. Ej:


- Explicación de la alimentación de cada placa. Cuanto voltaje y cuanto amperaje. Ej:


### SISTEMA DE SOFTWARE

En este caso, lo que se debe incluir en este apartado es:

  - Diagramas UML, esquemáticos de clases, librerías, máquinas de estados… Ej :


  - Interacciones entre scripts / programas divididos por función y entre el software y el usuario.

### SISTEMA FÍSICO (ENSAMBLAJES)

Todas las piezas que se vayan a fabricar y/o montar (ya sea mecanizados, corte laser, impresiones 3D, la cámara, sensores, botones…)

Solo los planos de solidworks o donde se haya diseñado el ensamblaje que luego irían al COST.


## Factilidad y costes

Junto con la lista de materiales explicada con brevedad anteriormente, ampliar aquí los precios de cada elemento del coche (BOM). Incluir la mano de obra es interesante también de cara a las competiciones.


## Viabilidad

- Tecnica y funcional: Que beneficios ofrece, la eficiencia, la facilidad de fabricación, instalación, uso, mantenimiento,…
- Económica: Por que diseñarlo y hacerlo nosotros, donde recortaríais, que impacto tendría… Esto no hace falta que sea muy detallado pero si que esta bien que aporteis ideas de mejoras de cara a futuras replicas o “comercializaciones”
- Respecto a otras soluciones de otros equipos, comerciales, etc

## Riesgos

Detallar todos los posibles puntos de fallo, vulnerabilidades y medidas a tomar para solventarlas. Diferenciar entre niveles de riesgo (Crítico – Alto – Medio – Bajo)

## Prototipado

Adjuntad fotos y explicación de cada versión FUNCIONAL que logréis fabricar. Tras las pruebas del prototipo (y por tanto la redacción de la documentación de las pruebas) podéis seguir ampliando este apartado en función de mejoras que hagáis.

# FASE DE PRUEBAS

En esta fase se van a comenzar a hacer todas las pruebas de inicio a fin del proyecto. Estas estas seguirán principalmente el siguiente esquema y es importante documentar todo esto y tratar de no realizar pruebas sin un plan de pruebas definido:

- Definición del plan de pruebas
- Herramientas utilizadas
- Detección de los puntos de fallo, problemas, resultados, conclusiones y medidas tomadas.

La fase de pruebas se dividirá en los siguientes grupos de pruebas:

- Pruebas unitarias
- Pruebas de integración
- Pruebas funcionales

## Pruebas Unitarias

En la fase de pruebas unitarias se espera comprobar que cada componente de cada subsistema funciona como esperamos que lo haga.

- Para las secciones de electrónica y driverless esto supone:
  - Probar actuadores
  - Probar sensores
  - Probar las placas
  - Probar la comunicación de las placas (de forma unitaria, con otra placa que sepamos 100% que sea capaz de leer y escribir, no entre placas nuevas)
  - Probar las pantallas
  - Etc…

Esto a veces no es posible en proyectos demasiado simples como es el caso del SDC y por su naturaleza la definición de pruebas unitarias coincide con las pruebas de integración o incluso las pruebas funcionales.

- Para el resto de las secciones:
  - Realizar simulaciones y validaciones para verificar que cumplen lo mínimo requerido.

Esto es similar a la función del SES en el caso de los monocascos. Y como pasa con algunos proyectos de electrónica o driverless, es posible que las pruebas unitarias se solapen con las de integración o las funcionales.

### Plan de pruebas

El plan de pruebas se debe planificar acorde con el objetivo de las pruebas unitarias. Se debe detallar para cada prueba el procedimiento, el resultado esperado y si lo cumple o no (adicionalmente se puede anotar en que falló o cual fue el resultado para ayudar al análisis posterior y a la iteración siguiente ya sea para solucionar los problemas o para mejorarlo).

Un ejemplo del plan de pruebas es el siguiente:

Pruebas del proyecto EL-12 (Gear Shift):

Subsistema 1: Actuadores
Prueba | Resultado Esperado | ¿Lo cumple? | Anotaciones
Comprobar que el actuador del cambio (Flatshifter) funciona al alimentarlo para que suba marcha según la datasheet. | El actuador debe de accionarse realizando el movimiento de subir marcha | Si/No
Comprobar que el actuador del cambio (Flatshifter) funciona al alimentarlo para que baje marcha según la datasheet. | El actuador debe de accionarse realizando el movimiento de bajar marcha | Si/No
Comprobar que el servo del embrague se mueve en todos los grados posibles mediante un código simple. | El servo se mueve en el rango completo | Si/No

Esta tabla debe realizarse para todas las posibilidades de funcionamiento de cada componente de cada subsistema.

### Herramientas utilizadas

Se deben citar todas las herramientas usadas en cada prueba unitaria junto con el propósito de utilizarlas (incluyendo si es posible un link a las webs de estas).

### Detección de puntos de fallo, problemas, resultados, conclusiones y medidas tomadas

Una vez habiendo realizadas las pruebas conforme al plan de pruebas (si hubiese alguna prueba realizada no contemplada previamente se debe documentar también en el apartado de plan de pruebas), procedemos al análisis de estas junto con una reflexión de posibles puntos de fallo o problemas que pudiesen causar en un futuro.

Lo ideal es que para cada problema encontrado o para cualquier posible punto de fallo, se detalle también que medidas se van a tomar para solucionarlo para poder modificarlos con tiempo antes de la implementación final.

Por último, incluimos las conclusiones a las que llegamos a raíz de los resultados.

## Pruebas de integración

En la fase de pruebas de integración se espera comprobar que cada componente de cada subsistema funciona como esperamos que lo haga dentro del propio subsistema.

- Para las secciones de electrónica y driverless esto supone:
  - Probar que una placa sea capaz de accionar actuadores con un código simple (es decir que se programen lo justo y necesario para accionar los actuadores de todas las formas posibles).
  - Probar que una placa es capaz de leer correctamente los sensores mediante un código simple.
  - Probar la comunicación entre las placas (aquí ya si que se comunican entre placas nuevas).
  - Etc…

Esto a veces no es posible en proyectos demasiado simples como es el caso del SDC y por su naturaleza la definición de pruebas unitarias coincide con las pruebas de integración o incluso las pruebas funcionales.

- Para el resto de las secciones:
  - Realizar el montaje y las pruebas de los ensamblajes, comprobar que las dimensiones son las correctas, que no ha habido errores de fabricación etc...

Nuevamente, como pasa con algunos proyectos de electrónica o driverless, es posible que las pruebas unitarias se solapen con las de integración o las funcionales.

Esta etapa es equivalente a el montaje y la corrección de posibles fallos, es posible que se necesite repetir esta fase en numerosas ocasiones hasta que no haya más fallos. Se debería empezar a plantear el comprobar si se van a cumplir los requisitos definidos en la fase de definición para evitar arrastrar errores graves a la última fase de pruebas.

### Alimentación y Conexiones

Este apartado es solo aplicable a las secciones de electrónica y driverless.

Se debe documentar el diagrama de conexiones final (con todos los cambios que hayan podido surgir en las pruebas unitarias) junto con la alimentación, incluyendo la información detallada referente a los datos de la batería).

### Plan de pruebas

El plan de pruebas se debe planificar acorde con el objetivo de las pruebas unitarias. Se debe detallar para cada prueba el procedimiento, el resultado esperado y si lo cumple o no (adicionalmente se puede anotar en que falló o cual fue el resultado para ayudar al análisis posterior y a la iteración siguiente ya sea para solucionar los problemas o para mejorarlo).

Un ejemplo del plan de pruebas es el siguiente:

Pruebas del proyecto EL-12 (Gear Shift):

Subsistema 1: Actuadores
Prueba | Resultado Esperado | ¿Lo cumple? | Anotaciones
Comprobar que el volante es capaz de subir de marcha | El actuador debe de accionarse realizando el movimiento de subir marcha | Si/No
Comprobar que el volante es capaz de bajar marcha | El actuador debe de accionarse realizando el movimiento de bajar marcha | Si/No
Con el motor arrancado, comprobar que el volante es capaz de embragar | El servo tira del embrague del motor y se desacopla el cambio de marchas | Si/No
Con el motor arrancado, comprobar que el volante es capaz de desembragar | El servo suelta el accionamiento del embrague del motor y este debe ser suave | Si/No

### Herramientas utilizadas

Se deben citar todas las herramientas usadas en cada prueba unitaria junto con el propósito de utilizarlas (incluyendo si es posible un link a las webs de estas).

### Detección de puntos de fallo, problemas, resultados, conclusiones y medidas tomadas

Una vez habiendo realizadas las pruebas conforme al plan de pruebas (si hubiese alguna prueba realizada no contemplada previamente se debe documentar también en el apartado de plan de pruebas), procedemos al análisis de estas junto con una reflexión de posibles puntos de fallo o problemas que pudiesen causar en un futuro.

Lo ideal es que para cada problema encontrado o para cualquier posible punto de fallo, se detalle también que medidas se van a tomar para solucionarlo para poder modificarlos con tiempo antes de la implementación final.

Por último, incluimos las conclusiones a las que llegamos a raíz de los resultados.

## Pruebas funcionales

En la fase de pruebas funcionales se espera comprobar todos los subsistemas son capaces de cumplir todas las funciones y requisitos del proyecto.

- Para las secciones de electrónica y driverless esto supone:
  - Probar que una placa sea capaz de accionar actuadores con el código final (es decir se accionen como se planeó que lo harían).
  - Probar que una placa es capaz de leer correctamente los sensores y que los valores de estos no solo sean correctos, sino que tengan el efecto deseado en el procesamiento de estos.
  - Probar que la comunicación entre todas las placas sea fiable y de la forma esperada.
  - Etc…
- Para el resto de las secciones:
  - Realizar la comprobación de que los mecanizados cumplen su función.
  - Comprobar que los proyectos que requieran de ajustes sean corregidos adecuadamente (p.ej.: mapeado del motor, ajustes de la dirección, pesos, etc).

Esta etapa es equivalente a los Tests de rodaje y simulaciones de pruebas de scruti.

### Plan de pruebas y comparación con requisitos iniciales

El plan de pruebas se debe planificar acorde con el objetivo de las pruebas unitarias. Se debe detallar para cada prueba el procedimiento, el resultado esperado y si lo cumple o no (adicionalmente se puede anotar en que falló o cual fue el resultado para ayudar al análisis posterior y a la iteración siguiente ya sea para solucionar los problemas o para mejorarlo).

Un ejemplo del plan de pruebas es el siguiente:

Pruebas del proyecto EL-12 (Gear Shift):

Subsistema 1: Actuadores
Prueba | Resultado Esperado | ¿Lo cumple? | Anotaciones
Estando en neutra y con el motor arrancado, comprobar que el volante es capaz de embragar | El actuador debe de accionarse realizando el movimiento de subir marcha. El indicador de neutra debe seguir encendido. | Si/No
Comprobar que el volante es capaz de subir de marcha de neutra a primera con fluidez | El actuador debe de accionarse realizando el movimiento de bajar marcha. Además, el indicador de neutra se apaga. | Si/No
Comprobar que el volante es capaz de desembragar mientras se pisa ligeramente el acelerador | El servo suelta el accionamiento del embrague del motor desembragando y este debe ser suave. Además, el coche debe empezar a moverse. | Si/No
Pisar el freno y el embrague del volante a la vez | El coche debe pararse. | Si/No
Comprobar que el volante es capaz de bajar marcha y pasar a neutra | El indicador de neutra se activa, indicando que este se ha quedado en punto muerto | Si/No

### Herramientas utilizadas

Se deben citar todas las herramientas usadas en cada prueba unitaria junto con el propósito de utilizarlas (incluyendo si es posible un link a las webs de estas).

### Resultados y conclusiones

Tras estas pruebas, los fallos deben ser mínimos (por supuesto, no debería haber ningún fallo de fabricación relacionado con incompatibilidades con otros sistemas puesto que eso debería haberse verificado en la etapa anterior).

Si tras las pruebas se encuentran ligeros fallos, estos se deben corregir e iterar sobre las pruebas de funcionalidades. Además, se debe comparar los resultados obtenidos con los requisitos marcados inicialmente y deben marcarse como cumplidos todos y cada uno de ellos para dar al proyecto como finalizado. En caso de no poder marcar alguno, se debe valorar si se trata de un requisito obligatorio o si ese requisito cambió durante el desarrollo. De ser obligatorio se debe corregir el sistema para cumplirlo, incluso pudiendo incluir un rediseño completo del proyecto implicando comenzar desde la etapa de diseño de nuevo y volver a realizar todas las etapas de las pruebas.

# Anexo

Aquí incluir todas las datasheets, los planos, y explicaciones adicionales.

NOMBRE DEL PROYECTO 2

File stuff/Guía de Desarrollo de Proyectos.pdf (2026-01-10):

# GUÍA DE DESARROLLO DE PROYECTOS


## UN ESTÁNDAR PARA EL DESARROLLO Y LA DOCUMENTACIÓN DE

## PROYECTOS

## Rocío Arranz

GUÍA DE DESARROLLO DE PROYECTOS | 2

ÍNDICE

OBJETIVO DE LA GUÍA

El objetivo de esta guía es facilitar el desarrollo de los proyectos, así como ayudar a estructurar la documentación. Dicha documentación se deberá completar de forma simultánea para dejar reflejadas todas las ideas, modificaciones, problemas, soluciones y conclusiones a las que la persona encargada del proyecto.

La guía plantea el flujo habitual en el desarrollo de un proyecto, enfocándose en la iteración y la mejora a partir de las pruebas realizadas, así como recomienda la obtención de feedback y el diseño de prototipos antes de la fabricación de la solución final.

FASES DEL DESARROLLO DE UN PROYECTO

Para el desarrollo de cada proyecto se sigue el siguiente cauce básico:


Dependiendo del proyecto, los objetivos de cada fase del cauce podrán ser ligeramente diferentes llegando incluso a obviar ciertas partes no relevantes o no aplicables para este. No obstante, el elemento común debe ser el mismo cauce.

FASE DE DEFINICIÓN DEL PROYECTO

En esta fase se va a definir el alcance del proyecto, incluyendo los objetivos, los requisitos, etc.

En concreto esta fase tiene la siguiente estructura:

- Resumen del proyecto
- Palabras clave/nomenclatura usada en el proyecto.
- Definición de los objetivos.
- Definición de los requisitos.

RESUMEN DEL PROYECTO

En este apartado se resume brevemente en que va a consistir el proyecto (p.ej.: en un cambio automático que facilite el cambio de marchas a los pilotos).

Con esta descripción, cualquier persona debería ser capaz de comprender para que sirve el proyecto.

PALABRAS CLAVE Y NOMENCLATURA

Debido a que usamos muchas siglas y palabras clave en el proyecto, debemos crear una guía que englobe todas estas para que cualquier persona que vaya a leer nuestra documentación sea capaz de comprender dichas siglas o palabras.

Se puede tomar como referencia el apartado de abreviaciones del documento de reglas de FSG:


DEFINICIÓN DE LOS OBJETIVOS

Los objetivos del proyecto son una abstracción de los requisitos, es una forma general de profundizar en el propósito del proyecto (p.ej.: los objetivos de hacer el cambio x es mejorar la aerodinámica del coche y reducir el peso).

DEFINICIÓN DE LOS REQUISITOS

Los requisitos del proyecto nacen de un análisis más exhaustivo del propósito del proyecto. Estos deben de tener en cuenta más factores, frecuentemente relacionados con posibles interferencias con otros proyectos o pueden surgir también en base a peticiones de los pilotos, aunque no lo especifiquen directamente, entre otras causas.

Se deben definir más en detalle y pueden surgir nuevos requisitos (que también se deben añadir en este apartado) para garantizar que cuando lleguemos a la solución final, el proyecto cumpla correctamente con las funciones exigidas sin tener necesidad de descartarlo y rediseñarlo de nuevo (p.ej.: incluir la información de las temperaturas del coche en la pantalla, mostrar la marcha engranada, mostrar las revoluciones, que la pantalla sea visible a la luz del sol…).

Estos requisitos se comprobarán en cada fase de pruebas en mayor o menor medida.

FASE DE DISEÑO

En esta fase, se comenzará a diseñar el proyecto en sí. Se diseñarán y esbozarán las primeras versiones del proyecto incluyendo:

DIAGRAMA GLOBAL DEL PROYECTO / SISTEMA

En este diagrama se definen todos los componentes de nuestro sistema / proyecto y los posibles subsistemas.

En caso de las secciones de electrónica y driverless, esta definición no significa lo mismo que para el resto de las secciones, por lo que lo que se debe de incluir en este apartado según dicha distinción:

PARA ELECTRÓNICA/DRIVERLESS:

En estas dos secciones se trabaja tanto como con ensamblajes 3D como con placas y software, y por esto mismo un proyecto puede tener diversos sistemas y cada uno de ellos poseer diferentes subsistemas. Para simplificar esto, la definición de sistema dentro de un proyecto de estas secciones puede ser:

- SISTEMA ELECTRÓNICO (HARDWARE / CABLEADO / ALIMENTACIÓN): Se considera el sistema completo al conjunto de placas, actuadores, sensores, las conexiones existentes y la alimentación de todas ellas. Y se hace la división en subsistemas conforme a cada componente del conjunto (p.ej.: subsistema de comunicación, subsistema de sensores, subsistema de procesamiento, etc).

En este caso, el material que se debe incluir es:
- Diagramas de placas (junto con su explicación básica del funcionamiento, si es demasiado detallada o larga mejor incluirla como anexo)
- Diagramas de cableado
- Diagramas de las interconexiones incluyendo una explicación de los pinout.
- Explicación de la alimentación de cada placa.
- SISTEMA DE SOFTWARE: En este, el software en sí el sistema completo, aunque se diferencian los subsistemas conforme al propósito de cada script / código / programa (p.ej.: interfaz de usuario, software CAN, cambio de marcha, máquina de estados, etc).

En este caso, lo que se debe incluir en este apartado es:
- Diagramas UML, esquemáticos de clases, librerías.
- Interacciones entre scripts / programas divididos por función y entre el software y el usuario.
- SISTEMA FÍSICO (ENSAMBLAJES): Este sistema conforma todos los diseños de piezas y/o ensamblajes del proyecto (como cajas, levas, ensamblaje de setas, o el propio volante incluso) que guarden relación directa con las secciones de electrónica o driverless. En ciertos proyectos esta parte conformará la mayor parte.

Por lo tanto, en este contexto se considera el ensamblaje principal como el sistema y los subsistemas son los subensamblajes y las piezas. En este caso se incluyen los planos y los planos explosionados (los mismos que se deben subir al COST).

PARA EL RESTO DE LAS SECCIONES:

El sistema conforma todos los diseños de piezas y/o ensamblajes del proyecto (como pletinas, alerones, el chasis) que no guarden relación directa con las secciones de electrónica o driverless.

Por lo tanto, en este contexto se considera el ensamblaje principal como el sistema y los subsistemas son los subensamblajes y las piezas. En este caso se incluyen los planos y los planos explosionados (los mismos que se deben subir al COST).

PROTOTIPADO

Junto con el diseño se aconseja prototipar todo lo que se pueda (no siempre es posible) para evitar derrochar tiempo esperando a productos terminados de cara a la iteración de la primera fase de pruebas.

El prototipado dependiendo de la sección tiene un concepto diferente, puede variar desde enchufar componentes en una protoboard a usar cartones como primeras versiones para obtener el feedback de pilotos y/o miembros del equipo.

FASE DE PRUEBAS

En esta fase se van a comenzar a hacer todas las pruebas de inicio a fin del proyecto. Estas estas seguirán principalmente el siguiente esquema:

- Definición del plan de pruebas
- Herramientas utilizadas
- Detección de los puntos de fallo, problemas, resultados, conclusiones y medidas tomadas.

Debido a que la fase de pruebas es una fase que se basa en la iteración continua, es posible que se deba rediseñar (y por lo tanto modificar el contenido definido en la fase de diseño). Esta etapa, igual que la anterior, diferencia entre las secciones de electrónica y driverless del resto de secciones. Por esta razón, describiremos lo que se espera documentar de las pruebas en función de esto.

La fase de pruebas se dividirá en los siguientes grupos de pruebas:

- Pruebas unitarias
- Pruebas de integración
- Pruebas funcionales

PRUEBAS UNITARIAS

En la fase de pruebas unitarias se espera comprobar que cada componente de cada subsistema funciona como esperamos que lo haga.

- Para las secciones de electrónica y driverless esto supone:
- Probar actuadores
- Probar sensores
- Probar las placas
- Probar la comunicación de las placas (de forma unitaria, con otra placa que sepamos 100% que sea capaz de leer y escribir, no entre placas nuevas)
- Probar las pantallas
- Etc…
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

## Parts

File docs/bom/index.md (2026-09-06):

# Bill of Materials (BOM)

## Overview

This page provides a comprehensive list of all components required to build the driverless kart. Component data is now stored in YAML files within each assembly folder, following the project structure.

!!! info "New BOM Management System"
    Components are now managed via separate YAML files in each assembly folder. The folder structure represents the BOM tree itself, eliminating synchronization issues.

## How to Add Components to BOM

Adding a new component is simple:

1. **Find the right folder** - Navigate to the appropriate assembly folder (e.g., `docs/assembly/steering/`)
2. **Edit the bom.yaml file** - Open the `bom.yaml` file in that folder
3. **Add your component** - Copy an existing component entry and modify it with your new component's details
4. **Include key information**:
   - `id`: unique identifier (e.g., "motor_controller_v2")
   - `part_number`: manufacturer part number
   - `description`: what it is
   - `quantity`: how many needed
   - `unit_cost`: price per unit
   - `suppliers`: where to buy it (name, url)

That's it! The component will automatically appear in BOM reports.

## BOM Structure

The BOM is organized by assembly with YAML files containing detailed component specifications:

```
docs/assembly/
├── powertrain/
│   ├── bom.yaml              # Motor, throttle pedal
│   ├── transmission/bom.yaml # Chain, sprockets
│   └── fasteners/bom.yaml    # All powertrain fasteners
├── steering/
│   ├── bom.yaml              # H-bridge, motor, sensor, coupling
│   └── fasteners/bom.yaml    # All steering fasteners
├── electronics/
│   ├── bom.yaml              # Orin, ESP32, DAC, level shifter
│   └── power/bom.yaml        # Battery cells, BMS, auxiliary battery
├── sensors/bom.yaml          # ZED2 camera, YOLOv11 models
└── hydraulics/bom.yaml       # Hydraulic brake components and service spares
```

## Assembly Overview

### 🔧 Powertrain Assembly
**Components**: Motor, transmission system, throttle control
- **Main Components**: [Powertrain BOM](../assembly/powertrain/bom.yaml)
- **Transmission**: [Transmission BOM](../assembly/powertrain/transmission/bom.yaml)
- **Fasteners**: [Powertrain Fasteners BOM](../assembly/powertrain/fasteners/bom.yaml)
- **Documentation**: [Powertrain Assembly](../assembly/powertrain/index.md)

**Key Components:**
- Kunray MY1020 3000W motor (€150.00)
- IRIS 219 chain and sprocket system (€40.00)
- Hall effect throttle pedal (€2.46)

### 🎮 Steering Assembly
**Components**: Motor, sensor, H-bridge, coupling
- **Main Components**: [Steering BOM](../assembly/steering/bom.yaml)
- **Fasteners**: [Steering Fasteners BOM](../assembly/steering/fasteners/bom.yaml)
- **Documentation**: [Steering Assembly](../assembly/steering/index.md)

**Key Components:**
- Cytron MD30C H-bridge (€45.00)
- AS5600 magnetic angle sensor (€2.00)
- 24V DC steering motor (€80.00)

### 💻 Electronics Assembly
**Components**: Computing, control, communication
- **Main Components**: [Electronics BOM](../assembly/electronics/bom.yaml)
- **Documentation**: [Kart Medulla (ESP32-S3)](../assembly/electronics/kart-medulla/index.md)

**Key Components:**
- NVIDIA Jetson AGX Orin (€1500.00)
- ESP32-S3-WROOM-1-N16R8 microcontroller (16 MB flash, 8 MB octal PSRAM; MCU of the Kart Medulla PCB; ~€5)
- ESP32-WROOM-32 microcontroller (€3.50, retired — was hand-wired in the kart before the Medulla PCB)
- Custom Orin adapter board (€25.00)

### ⚡ Power Assembly
**Components**: Main battery pack, BMS, auxiliary power
- **Main Components**: [Power BOM](../assembly/electronics/power/bom.yaml)
- **Documentation**: [Power Assembly](../assembly/electronics/power/battery.md)

**Key Components:**
- 52x Molicel P42A cells in 13S4P (€234.00)
- Jiabaida Smart BMS 100A (€85.00)
- 12V auxiliary battery (€60.00)

### 📷 Sensors Assembly
**Components**: Vision system, AI models
- **Main Components**: [Sensors BOM](../assembly/sensors/bom.yaml)
- **Documentation**: [Sensors Assembly](../assembly/sensors/camera.md)

**Key Components:**
- Stereolabs ZED2 stereo camera (€450.00)
- Custom YOLOv11 cone detection model

### 🛑 Hydraulic Braking Assembly
**Components**: Installed brake circuit and compatible service spares
- **Main Components**: [Hydraulics BOM](../assembly/hydraulics/bom.yaml)
- **Documentation**: [Hydraulics Assembly](../assembly/hydraulics/index.md)

**Key Components:**
- Legacy Tony Kart BS1-family brake pump, caliper, rear disc and hoses (installed; exact fitted part numbers need physical confirmation)
- Catalogue-era BS1/BS2 pump spare (€176.95)
- Catalogue-era pre-2000 BS1 rear-caliper spare (€193.95)
- BS1/BS3 steel-braided hose kit (€140.00)
- Newfren replacement pad set (supplier listing: AUD $71.50; confirm fit before ordering)

## Estimated Project Costs

| Assembly | Estimated Cost | Key Items |
|---|---|---|
| **Powertrain** | **€195** | Motor (€150), transmission (€40), fasteners (€5) |
| **Steering** | **€135** | H-bridge (€45), motor (€80), sensor (€2), fasteners (€8) |
| **Electronics** | **€1530** | Orin computer (€1500), ESP32 (€4), adapter (€25) |
| **Power** | **€380** | Li-ion cells (€234), BMS (€85), 12V battery (€60) |
| **Sensors** | **€450** | ZED2 camera (€450) |
| **Total** | **€2690** | *Excludes chassis, wiring, mechanical hardware* |

!!! warning "Cost Estimates"
    Prices are approximate and subject to change. Always verify current pricing from suppliers.

## Component Status

### ✅ Active Components
Currently used and functional in the kart.

### ⚠️ Needs Replacement
Known to be damaged or worn:
- 219 aluminum rear sprocket (damaged from incompatible chain use)

### 🔧 Custom Components
Require fabrication:
- Custom 219 front sprocket (laser cut for 10mm shaft)
- Orin adapter board (EasyEDA design available)
- Battery pack assembly (professional assembly recommended)

## Supplier Information

### Primary Suppliers
- **Electronics**: Mouser, Digi-Key, Adafruit
- **Karting Parts**: KPS Racing
- **Batteries**: Authorized Molicel distributors
- **Vision Systems**: Stereolabs
- **General Components**: AliExpress, Amazon (for non-critical parts)

### Quality Guidelines
- ✅ Use official distributors for critical electronic components
- ✅ Verify specifications before ordering
- ⚠️ AliExpress/Amazon acceptable for mechanical parts and sensors
- ❌ Avoid counterfeit components for safety-critical systems

## Assembly Priority

1. **Power System** - Battery pack, BMS, charging setup
2. **Core Electronics** - Orin computer, ESP32 microcontroller
3. **Sensors** - ZED2 camera, angle sensors
4. **Propulsion** - Motor, controller, transmission
5. **Steering** - Motor, H-bridge, coupling
6. **Integration** - Wiring, mounting, calibration

## Working with YAML BOM Files

### Adding New Components
1. Locate the appropriate assembly folder
2. Edit the `bom.yaml` file
3. Follow the existing structure for consistency
4. Include all required fields: id, part_number, description, quantity, cost, suppliers

### YAML File Structure
```yaml
assembly: "assembly_name"
description: "Assembly description"
components:
  - id: "unique_component_id"
    part_number: "MANUFACTURER-PART-NUMBER"
    description: "Component description"
    quantity: 1
    unit_cost: 0.00
    currency: "EUR"
    status: "active"
    criticality: "essential"
    suppliers:
      - name: "Supplier Name"
        url: "https://supplier.com/product"
        verified: true
    specifications:
      key: "value"
    notes: "Additional information"
```

### Future Automation
A BOM aggregation script is planned to automatically generate:
- Complete cost summaries
- Supplier contact lists
- Component status reports
- Assembly checklists

---

*This BOM system reflects the complete restructure from hardware-based to assembly-based organization, with component data stored in YAML files following the project's folder structure.*

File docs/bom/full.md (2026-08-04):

# Full BOM (shareable)

A consolidated, shareable bill of materials for the autonomous kart. Two cost columns:

- **Team cost (€)** — what the team actually paid to acquire the part. Donated and sponsored items are €0.
- **Market cost (€)** — what a new team would pay to buy the same part today, with no donations or sponsorship.

Use the per-assembly `bom.yaml` files for the full machine-readable record (part numbers, suppliers, specs). This page is the human-readable summary suitable for sharing.

!!! info "Source legend"
    - **Donated** — given to the team by an external partner (kart shop, sponsor, alumnus).
    - **Sponsored** — supplied at no cost (or heavily discounted) by a named sponsor in exchange for visibility.
    - **Purchased** — bought by the team from project funds.
    - **Salvage** — pulled from a discarded appliance / scrap (e.g. massage-chair motor). Team cost €0; market cost is the price of an equivalent new part.
    - **Custom** — designed and fabricated by the team (cost = materials + service like PCB / laser cut / 3D-print filament).

!!! note "VAT and shipping"
    All amounts are in EUR and include VAT and shipping where applicable. Some team purchases were intra-EU B2B with VAT reverse-charged (invoiced at 0 % VAT); in those cases the team-cost column reflects the amount actually transferred to the supplier. Market-cost figures are *retail incl. 21 % Spanish VAT* — what a new team paying out of pocket would see.

Numbers marked **`~`** are estimates pending confirmation from receipts.

---

## Chassis

| Part | Qty | Source | Team cost (€) | Market cost (€) | Notes |
|---|---:|---|---:|---:|---|
| Tony Kart Extreme frame (1999 ICA homologation) | 1 | Donated | 0 | ~800 | Used competition kart chassis. Verde Tony 30/32 mm chromoly, 40 mm rear axle. Equivalent used kart chassis market estimate. |
| Wheels and tyres (slicks set) | 1 set | Donated | 0 | ~200 | Came with the donated chassis. New set cost depends on compound. |
| Brake system (mechanical, OEM kart) | 1 | Donated | 0 | ~150 | Original kart hydraulic brake retained. |
| Steering column + tie rods | 1 | Donated | 0 | ~80 | Stock with chassis. |

**Chassis subtotal — team: €0 · market: ~€1230**

---

## Powertrain

| Part | Qty | Source | Team cost (€) | Market cost (€) | Notes |
|---|---:|---|---:|---:|---|
| Kunray MY1020 brushless motor + controller, 72 V 3000 W | 1 | Purchased | 150 | 150 | 10 mm shaft, no keyway. |
| IRIS 219 chain (100 links) | 1 | Purchased | 15 | 15 | KPS Racing. |
| 219 aluminium rear sprocket | 1 | Purchased | 20 | 20 | Currently damaged — needs replacement. |
| Custom 10 mm-bore 219 front sprocket (laser cut) | 1 | Custom | 5 | 5 | Material + laser-cut service. |
| Hall-effect throttle pedal (SS49E) | 1 | Purchased | 2.50 | 2.50 | AliExpress. |

**Powertrain subtotal — team: ~€192.50 · market: ~€192.50**

---

## Steering

| Part | Qty | Source | Team cost (€) | Market cost (€) | Notes |
|---|---:|---|---:|---:|---|
| Cytron MD25HV H-bridge (25 A, 7–58 V) | 1 | Purchased | 55 | 55 | Replaces older MD30C. |
| 24 V DC steering motor (driven from the battery) | 1 | Salvage | 0 | ~50 | Pulled from a discarded massage chair. Drives the steering through the 11:1 3D-printed planetary below. Has ~2 kW stall reserve (rarely hit; normal steering work is ~47 W). Off-the-shelf wiper motors are noted as **interesting alternatives** in the [steering motor options](../assembly/steering/motor-options.md), not as replacements. |
| 3D-printed planetary reducer, **15 : 1** (PLA/PETG) | 1 | Custom | ~6 | ~6 | ~150 g filament @ €25/kg + 4× 608 bearings (~€2) + M3 hardware. Print time on team printer not costed. Gives the salvage motor the torque headroom needed to cover edge cases without procurement. |
| AS5600 magnetic angle sensor module | 1 | Purchased | 2 | 2 | I²C, 12-bit. |
| 10 mm shaft coupling | 1 | Purchased | 15 | 15 | Aluminium. |
| Steering fasteners (M3/M6/M8 set) | — | Purchased | ~5 | ~5 | See `steering/fasteners/bom.yaml`. |

**Steering subtotal — team: ~€83 · market: ~€133**

---

## Electronics — Compute & control

| Part | Qty | Source | Team cost (€) | Market cost (€) | Notes |
|---|---:|---|---:|---:|---|
| NVIDIA Jetson AGX Orin Developer Kit (64 GB) | 1 | Purchased | 1857.29 | ~2200 | Silicon Highway invoice 2023-04: net €1 821.29 + €36 shipping, intra-EU reverse charge (VAT 0 % on invoice). True project cost is **~€2 247** once URJC self-accounts the 21 % reverse-charge VAT[^vat]; this column shows what was actually transferred to the supplier. Today's retail incl. 21 % VAT for the 64 GB devkit is ~€2 200. |
| Custom Orin adapter PCB (v1.0) | 1 | Custom | ~25 | ~25 | EasyEDA design + JLCPCB-style fabrication. |
| ESP32-WROOM-32 dev board (retired) | 1 | Purchased | ~3.50 | ~3.50 | Was flying-wired in the kart before the Kart Medulla PCB; no longer installed. |
| ESP32-S3-WROOM-1-N16R8 dev board (Kart Medulla) | 1 | Purchased | 8.69 | 8.69 | AliExpress, ordered 2026. MCU of the Kart Medulla interface PCB installed in the kart. Octal PSRAM makes GPIO 33–37 unusable; the pinout leaves them free. |
| MCP4922 dual 12-bit SPI DAC | 1 | Purchased | ~3 | ~3 | `CMD_ACC` and `CMD_BRAKE` analogue out on the Medulla PCB. Replaced the originally planned MCP4728 (I²C) in 2026-04. |
| Kart Medulla interface PCB (bare board) | 1 | Custom | ~15 | ~15 | Fabricated and installed in the kart. Estimate — small 2-layer board, JLCPCB-style. |
| Green push-in terminal blocks, 3-pin (Medulla CN1–CN10) | 10 | Purchased | ~10 | ~10 | Fitted. Replaced the Dupont harness. |
| Logic-level shifters + op-amps + passives (incl. motor-Hall conditioning) | — | Purchased | ~10 | ~10 | Fitted on the Medulla PCB. Reads the motor's three Hall sensors; no external wheel-speed sensors needed. |
| 500 GB M.2 NVMe SSD (Orin storage) | 1 | Salvage | 0 | ~40 | Pulled out of a laptop during a 2 TB upgrade. Big improvement on dev/install work for the Orin (`apt`, builds, repos); no effect on the runtime FPS of the autonomy stack. |

**Compute & control subtotal — team: ~€1932 · market: ~€2315**

---

## Electronics — Power (traction battery)

The traction pack was assembled by the team from individual components rather than bought as a unit. Listing the breakdown so a new team can reproduce it. There is **no separate 12 V auxiliary battery** — the 12 V rail for sensors is generated from the traction pack via a buck regulator (see wiring diagram).

| Part | Qty | Source | Team cost (€) | Market cost (€) | Notes |
|---|---:|---|---:|---:|---|
| Molicel P42A 21700 Li-ion cell | 52 | Purchased | 198 | ~234 | 13S4P pack. NKON bulk: 60 cells for €230 (€3.83/cell), 52 used in the pack. Retail ~€4.50/cell. |
| Jiabaida JBD-SP22S003B smart BMS, 100 A | 1 | Purchased | 85 | 85 | 13S, Bluetooth + UART. |
| Pure-nickel strip (0.15 × 8 mm, ~2 m) | 1 | Purchased | ~10 | ~10 | For series/parallel interconnects. |
| Cell holders (4×13 21700 plastic frames) | 1 set | Purchased | ~8 | ~8 | AliExpress. |
| Kapton tape + fish-paper insulators | — | Purchased | ~5 | ~5 | Insulation under nickel. |
| Heat-shrink + double-sided tape | — | Purchased | ~5 | ~5 | Pack assembly. |
| 3D-printed enclosure (PETG, ~600 g) | 1 | Custom | ~15 | ~15 | Filament cost only; print time on team printer. |
| Fire-retardant foam liner (mica/ceramic blanket) | 1 | Purchased | ~15 | ~15 | Inside the enclosure. |
| Anderson SB50 / XT90 pack connectors | 2 | Purchased | ~10 | ~10 | Main + charge ports. |
| 8 AWG silicone power cable (~1 m) | 1 | Purchased | ~6 | ~6 | Pack output. |
| 12 V buck regulator (from 48 V pack) | 1 | Purchased | ~10 | ~10 | Replaces the previous 12 V lead-acid aux battery. |

**Power subtotal — team: ~€367 · market: ~€403**

---

## Sensors

| Part | Qty | Source | Team cost (€) | Market cost (€) | Notes |
|---|---:|---|---:|---:|---|
| Stereolabs ZED 2 stereo camera | 1 | Purchased | 450 | 450 | Primary perception sensor. |
| Custom YOLOv11 cone-detection model | 1 | Custom | 0 | 0 | Trained in-house. |
| Motor Hall sensors (×3) | 0 | Built-in | 0 | 0 | Internal to the Kunray motor; read via level shifters on the Kart Medulla PCB. No external sensors needed. |

**Sensors subtotal — team: €450 · market: €450**

---

## Pneumatic Braking System (sponsored)

The full pneumatic ASB / EBS stack is supplied by **Festo Automation, S.A.U.**, an official sponsor of the team. Item-level part numbers, datasheets, quantities and reuse status are tracked in the [Pneumatic Braking BOM](../assembly/pneumatic-braking/bom.md). Per-line market prices are intentionally redacted on this public page (see note below).

!!! note "Why prices are redacted in this section"
    Per-component market values for the Festo-supplied parts are not published here, as a courtesy to the sponsor relationship and consistent with the confidentiality obligations of the team's collaboration agreement with Festo. Public distributor reference prices for these parts have been collected and are kept in the team's internal Drive for project bookkeeping. The team's monetary cost for these items is **€0**; the team's contribution under the agreement is visibility (logo on the kart, social-media tagging, sponsor listing on the team site, invitations to Formula Student events) rather than a cash payment.

| Festo PN | Description | Qty | Source | Team cost (€) | Market value (€) |
|---|---|---:|---|---:|---:|
| 8084714 | ADN-S-50-45-I-P-A pneumatic actuator | 1 | Sponsored | 0 | redacted |
| 8035174 | VUVS-LT25-M32U-MD-G14-F8 EBS electrovalve (NO) | 1 | Sponsored | 0 | redacted |
| 8035167 | VUVS-LT25-M32C-MD-G14-F8 ASB electrovalve (NC) — spare, not in validated circuit | 1 | Sponsored † | 0 | redacted |
| 571293 | VPPM-8L-L-1-G14-0L10H-V1P-S1C1 proportional regulator | 1 | Sponsored † | 0 | redacted |
| 6682 | OS-1/4-B shuttle valve / OR gate | 1 | Sponsored † | 0 | redacted |
| 527690 | MS4-LR-1/4-D7-AD10 low-pressure regulator | 1 | Sponsored † | 0 | redacted |
| 567465 | SDE5-D10-NF-Q6E-V-M8 pressure sensor (0–10 bar) | 2 | Sponsored | 0 | redacted |
| 197384 | PUN-H-6X1-BL pneumatic tubing | 3 m | Sponsored | 0 | redacted |
| 2029 | CK-1/4-PK-4 push-in fitting | 15 | Sponsored | 0 | redacted |
| 8030236 | NPFC-T-3G14-F threaded T-adapter | 2 | Sponsored | 0 | redacted |
| 4469 | LCK-1/8-PK-4 elbow fitting | 1 | Sponsored | 0 | redacted |
| 2316 | U-1/4 silencer | 3 | Sponsored | 0 | redacted |
| 2307 | U-1/8 silencer | 1 | Sponsored | 0 | redacted |
| 542256 | NEBU-M12W8-K-2-N-LE8 M12 cable (VPPM control) | 1 | Sponsored † | 0 | redacted |
| 541333 | NEBU-M8G3-K-2.5-LE3 M8 cable (sensor wiring) | 2 | Sponsored | 0 | redacted |
| 8030801 | VACF-B-B2-5 solenoid coil (ASB valve) — spare, not in validated circuit | 1 | Sponsored | 0 | redacted |
| 151687 | MSSD-EB valve-coil connector | 2 | Sponsored | 0 | redacted |
| — | Sensata PTE/700-33 hydraulic pressure sensor | 1 | Sponsored | 0 | redacted |

**EBS subtotal — team: €0. Market values redacted under the Festo sponsorship agreement.**

† Items marked with the dagger were requested under the current Festo sponsorship cycle and are pending delivery at time of writing — the rest of the stack is reused from earlier sponsorship cycles and is already on the kart.

> The pneumatic schematic and component photos live under [Pneumatic Braking](../assembly/pneumatic-braking/index.md). The 12 V air compressor + tank is on the planned-purchase list but not yet on the kart, so it isn't counted here.

---

## Wiring & misc hardware

| Part | Qty | Source | Team cost (€) | Market cost (€) | Notes |
|---|---:|---|---:|---:|---|
| Powertrain fasteners (M6/M8 + nuts) | — | Purchased | ~5 | ~5 | See `powertrain/fasteners/bom.yaml`. |
| 24 V → 5 V / 3.3 V buck converters | 2 | Purchased | ~6 | ~6 | Rail generation. |
| XT90-S anti-spark connector (pack switch) | 1 | Purchased | ~10 | ~10 | Currently doubles as the precharge mechanism. A proper main contactor should be added in a future revision. |
| Generic harness wire, lugs, heat-shrink | — | Purchased | ~30 | ~30 | Whole-vehicle harness. |
| Wheel-axle bearings (replacement set) | — | Purchased | ~20 | ~20 | Replaced during build. |

**Wiring subtotal — team: ~€71 · market: ~€71**

---

## Totals

| Section | Team cost (€) | Market cost (€) |
|---|---:|---:|
| Chassis | 0 | ~1230 |
| Powertrain | ~192.50 | ~192.50 |
| Steering | ~83 | ~133 |
| Electronics — compute & control | ~1932 | ~2315 |
| Electronics — power | ~367 | ~403 |
| Sensors | 450 | 450 |
| Pneumatic braking (ASB + EBS) | 0 | redacted |
| Wiring & misc hardware | ~71 | ~71 |
| **Total (transferred to suppliers)** | **~€3095** | redacted |
| Reverse-charge VAT on the Orin (self-accounted by URJC) | +~390 | — |
| **Total incl. VAT actually borne by the project** | **~€3485** | redacted |

The market column for the EBS section is redacted under the Festo sponsorship agreement, which makes the page-level market total non-disclosable as well. Excluding the Festo-supplied stack, the rest of the kart at retail comes to ~€4 815 incl. VAT (chassis ~€1 230, powertrain ~€192.50, steering ~€133, compute & control ~€2 315, power ~€403, sensors €450, wiring ~€71).

The ~€1.5 k delta between team cost and that priced-but-non-Festo market subtotal comes from the donated chassis (~€1 230), the salvaged steering motor (~€50), and the salvaged Orin SSD (~€40).

---

## Tooling required to build / maintain the kart

Not consumed by the build, but required to do it. Costs here are rough market prices for hobby/entry-grade equipment that's adequate for this project — a new team can borrow most of these from a university workshop.

### Mechanical

| Tool | Used for | Indicative cost (€) |
|---|---|---:|
| TIG welder (small, 200 A class) | Chassis modifications, motor mount welding | ~600 |
| MIG welder (entry hobby) | Battery box / mounting brackets | ~300 |
| Angle grinder (115 mm) + cutting/flap discs | General metalwork | ~80 |
| Cordless drill + HSS bit set | Mounting holes, brackets | ~120 |
| Bench vice (100 mm) | Holding parts for cutting / filing | ~70 |
| Hand files, deburring tools | Edge finishing | ~30 |
| Torque wrench set (5–25 Nm and 20–100 Nm) | Critical fasteners (steering, motor mount, axle) | ~100 |
| Metric hex key set + sockets + ratchet | Generic fastening | ~80 |
| Digital caliper (0–150 mm) | Layout / verification | ~25 |
| Tape measure, combination square | Layout | ~15 |

### Fabrication (outsource-friendly)

| Tool | Used for | Indicative cost (€) |
|---|---|---:|
| 3D printer (Bambu A1 / P1S class) | Battery box, sensor mounts, brackets | ~400 |
| Laser cutting (sheet metal / acrylic) | Front sprocket, brackets — outsourced per cut | per-job |
| PCB fabrication (JLCPCB-style) | Orin adapter, Kart Medulla — outsourced | per-job |

### Electronics

| Tool | Used for | Indicative cost (€) |
|---|---|---:|
| Soldering station (60 W, temp controlled) | Through-hole and SMD rework | ~100 |
| SMD hot-air station | QFN/QFP rework | ~80 |
| Wire stripper / crimper (10–24 AWG) | Signal and power harness | ~30 |
| Heavy-duty crimper (8–2 AWG) | Battery cables, lugs | ~60 |
| Digital multimeter | Continuity, voltage, current | ~50 |
| Oscilloscope (entry, ~50 MHz) | UART/I²C/CAN debug, PWM checks | ~250 |
| USB–CAN adapter | CAN bus monitoring | ~40 |
| 12 V / 24 V bench PSU (or smart battery charger) | Aux battery test, sensor power | ~80 |

### Battery assembly (specific tools)

| Tool | Used for | Indicative cost (€) |
|---|---|---:|
| Spot welder (capacitor or pulse, ~1 kJ) | Welding nickel strip to cells | ~150 |
| Cell-level fuse wire / fuse holders | Per-cell fusing (safety) | ~10 |
| IR thermometer | Verifying weld/joint temperature | ~25 |
| Insulating mat + safety glasses + nitrile gloves | PPE for cell handling | ~30 |

**Tooling indicative total (one-time): ~€2700** — most can be borrowed; only consumables and PCB/laser-cut service are recurring.

---

## What this page deliberately omits

- **Invoice numbers, vendor account IDs, supplier-specific PO numbers** — kept in the team's private archive, not in this public repo.
- **Donor names** beyond the agreed-public sponsors. If you need credits/acknowledgements, see the team contact page.
- **Per-cell serial numbers** for the traction pack — tracked in the private inventory.

For machine-readable component data (part numbers, specs, suppliers) consult the per-assembly `bom.yaml` files linked from [BOM overview](index.md).

[^vat]: Intra-EU B2B sales are zero-rated on the supplier side under reverse charge (Council Directive 2006/112/EC, Art. 138 + Art. 196). The buyer self-accounts VAT in its own return. URJC, as a public university whose activity is mainly non-economic, generally has no (or very limited) VAT-deduction right, so the self-accounted 21 % is a real cost to the project — paid to the Spanish tax agency rather than to the supplier. Buying the same kit from outside the EU would not be tax-free either: import VAT (21 %) is charged at the border, plus a courier handling fee.

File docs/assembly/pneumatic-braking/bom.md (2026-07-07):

# Bill of Materials

All pneumatic ports standardized to **G1/4** unless noted. Tubing is **6 mm OD / 4 mm ID** throughout. FS 2026 rules: push-in fittings are allowed for ASB/EBS, but we prefer compression (union nut) fittings. Exception: the SDE5 sensor has an integrated QS-6 push-in port.

This BOM covers the **validated design** (parallel VPPM + EBS, merged by the OR valve, **no series ASB isolation valve** — see the [design page](index.md)). The ASB valve, its coil, and its connector are still listed below because we own them, but they are **not part of the validated circuit** (kept as spares).

The BOM follows the pneumatic path from compressor/tank to actuator.

## Compressor & Tank

Salvaged portable inflator (12 V motor + piston only — recovered from a broken Xiaomi-class unit, no original electronics) charges a Festo CRVZS-0,75 reservoir. Target charge **10 bar**; the compressor needs its own over-pressure cutoff (current + temperature) since it lost the factory control. Both items are in the [AI Inventory](https://www.notion.so/34a78747314381a2abe9c158bf7c0a5c). *(Supersedes the VEVOR 6 L compressor+tank used in the May 2026 validation — source side not yet re-validated.)*

| Status | Part No. | Description | Link |
|---|---|---|---|
| Have | 160235 | Festo CRVZS-0,75 reservoir — 0.75 L stainless, PS 16 bar / PT 24 bar, G1/4, TÜV. Charged to 10 bar; sized for 3 brake activations 10→6 bar | [datasheet](https://ftp.festo.com/Public/PNEUMATIC/SOFTWARE_SERVICE/DataSheet/EN_GB/160235.pdf) · [Festo](https://www.festo.com/us/en/a/160235/) |
| Have | — | Salvaged portable inflator, 12 V motor + piston (Xiaomi-class, no electronics) | — |

## Tubing

| Status | Part No. | Description | Festo link |
|---|---|---|---|
| Buy | 197384 | PUN-H-6X1-BL tubing, 6 mm OD / 4 mm ID, blue (3 m) | [Festo](https://www.festo.com/es/es/a/197384/) |

Datasheet (local): [`197384datasheet.pdf`](../../assets/datasheets/197384datasheet.pdf)

## Pressure Sensor 1 (tank side, before regulator)

Monitors tank/supply pressure. Connects directly to tubing via integrated 6 mm push-in fitting. **Measurement range: 0–10 bar; overload pressure 15 bar** (Festo SDE5 series operating instructions).

| Status | Part No. | Description | Festo link |
|---|---|---|---|
| Reuse | 567465 | SDE5-D10-NF-Q6E-V-M8 pressure sensor, 0-10 bar, 0-10V analog, M8 connector, QS-6 push-in | [Festo](https://www.festo.com/es/es/a/567465/) |

Datasheet (local): [`567465datasheet.pdf`](../../assets/datasheets/567465datasheet.pdf)

> **Warning:** This sensor **measures** 0–10 bar but **survives to 15 bar** (overload). The tank now charges to **10 bar**, so it reads full-scale at the top of its range; above 10 bar it stays intact but saturates (reads a flat 10 — you go blind on the exact value). Since the salvaged compressor has no factory over-pressure cutoff, the compressor control + the (pending) non-adjustable safety relief valve must keep the tank at ≤10 bar so the reading stays meaningful.

> **Supply voltage — needs a boost from the 12 V rail (TODO).** The SDE5 requires a **15–30 V DC** supply (datasheet), but the kart runs a single 12 V rail (48 V → 12 V buck). Both SDE5 sensors therefore need a small step-up (boost) converter — planned, not yet fitted. The 0–10 V analog output is unaffected and feeds the ESP32 ADC as usual.

## Manual Valve (brake release / isolation)

Manual valve for brake release during maintenance and system isolation. Reuse existing on-hand valve.

| Status | Part No. | Description | Notes |
|---|---|---|---|
| Reuse | — | Manual valve, G1/4 | On-hand from previous seasons |

## Low-Pressure Regulator

Adjustable regulator to set maximum system working pressure downstream of the tank. Updated to **D7** variant for higher output range (0.5-12 bar vs D6's 0.5-10 bar).

| Status | Part No. | Description | Festo link |
|---|---|---|---|
| Buy | 527690 | MS4-LR-1/4-D7-AD10 pressure regulator, G1/4, 0.5-12 bar | [Festo](https://www.festo.com/es/es/a/527690/) |

Datasheet (local): [`527690datasheet.pdf`](../../assets/datasheets/527690datasheet.pdf)

> **Note:** The D7-AD10 subtype is selected within the same Festo product page as the D6 variant. The D6 maxes out at 7 bar (confirmed on unit label: p2 max 7 bar / 105 psi), which is too low for our system. The D7 extends output to 0.5-12 bar — there is no intermediate variant capping at 10 bar.

> **Warning — max system pressure is 10 bar.** The D7 regulator can output up to 12 bar, but all downstream components are rated at 10 bar or below (VUVS valves: 10 bar, SDE5 sensors: 10 bar, ADN-S actuator: 10 bar, VPPM inlet: 11 bar). **Never set the regulator above 10 bar** or downstream components may be damaged. There is no MS4-LR variant that caps at exactly 10 bar (D6 = 7 bar, D7 = 12 bar), so operational discipline or a downstream relief valve is required.

## Pressure Sensor 2 (regulated side, before valves)

Monitors regulated pressure entering the valve stage. Same model as sensor 1.

| Status | Part No. | Description | Festo link |
|---|---|---|---|
| Buy | 567465 | SDE5-D10-NF-Q6E-V-M8 (second unit) | [Festo](https://www.festo.com/es/es/a/567465/) |

Datasheet (local): [`567465datasheet.pdf`](../../assets/datasheets/567465datasheet.pdf)

## EBS Electrovalve (emergency braking)

Normally-open solenoid valve. When powered (driving): closed. When unpowered (emergency): opens and delivers full supply pressure to the actuator. **Max operating pressure: 10 bar** (2.5-10 bar range).

| Status | Part No. | Description | Festo link |
|---|---|---|---|
| Reuse | 8035174 | VUVS-LT25-M32U-MD-G14-F8, 3/2-way, Normally Open, G1/4, 2.5-10 bar | [Festo](https://www.festo.com/es/es/a/8035174/) |
| | 575488 | [Datasheet (local)](../../assets/datasheets/575488datasheet.pdf) | (matches VUVS-L25-M32U-MD-G14-F8) |

## ASB Electrovalve (VPPM supply isolation) — *not in validated circuit*

Normally-closed solenoid valve that would sit in series before the VPPM to cut its supply on power loss. **Removed from the validated design** — the VPPM blocks all ports when unpowered and the OR valve already isolates the branch, so this valve is redundant (see [Why no isolation valve in series with the proportional valve](index.md#why-no-isolation-valve-in-series-with-the-proportional-valve)). We own the part; kept as a spare. **Max operating pressure: 10 bar** (2.5-10 bar range).

| Status | Part No. | Description | Festo link |
|---|---|---|---|
| Spare | 8035167 | VUVS-LT25-M32C-MD-G14-F8, 3/2-way, Normally Closed, G1/4, 2.5-10 bar | [Festo](https://www.festo.com/es/es/a/8035167/) |

## VPPM Proportional Valve (ASB)

Proportionally controls brake pressure during autonomous driving. All ports blocked when unpowered (see [VPPM analysis](index.md#vppm-unpowered-behavior-the-datasheet-evidence)). **Max inlet pressure: 11 bar** (port 1). Output regulation range: 0-10 bar.

| Status | Part No. | Description | Festo link |
|---|---|---|---|
| Buy | 571293 | VPPM-8L-L-1-G14-0L10H-V1P-S1C1, 0-10 bar output, max 11 bar inlet, 0-10V setpoint, G1/4 | [Festo](https://www.festo.com/es/es/a/571293/) |
| | | [VPPM catalog documentation (local)](../../assets/datasheets/205274_documentation.pdf) | [online](https://www.festo.com/media/catalog/205274_documentation.pdf) |
| | | [Part-specific datasheet (local)](../../assets/datasheets/VPPM_en.pdf) | [online](https://www.festo.com/us/en/a/571293/) |

## Shuttle Valve (OR valve)

Ball-type shuttle valve that merges the EBS and VPPM output lines. Whichever side has higher pressure pushes the ball to seal the other port. **Required** — it stops the active branch from losing its air through the inactive branch's open exhaust (see [Why the OR / shuttle valve is required](index.md#why-the-or-shuttle-valve-is-required)).

| Status | Part No. | Description | Festo link |
|---|---|---|---|
| Buy | 6682 | OS-1/4-B shuttle valve, G1/4 | [Festo](https://www.festo.com/es/es/a/6682/) |

## Pneumatic Actuator

Spring-return cylinder. **G1/8 ports** — requires G1/4 → G1/8 adapter. **Max operating pressure: 10 bar** (0.4-10 bar for 50mm bore).

| Status | Part No. | Description | Festo link |
|---|---|---|---|
| Reuse | 8084714 | ADN-S-50-45-I-P-A, bore 50 mm, stroke 45 mm, G1/8, 0.4-10 bar | [Festo](https://www.festo.com/gb/en/a/8084714/) |

Datasheet (local): [`adn-s-enus.pdf`](../../assets/datasheets/adn-s-enus.pdf)

## Compression Fittings

| Status | Part No. | Qty | Description | Festo link |
|---|---|---|---|---|
| Buy | 2029 | ~15 | CK-1/4-PK-4 straight, G1/4 → tube 6 mm (all valve ports, NPFC-T ports, and general connections) | [Festo](https://www.festo.com/es/es/a/2029/) |
| Buy | 8030236 | 2 | NPFC-T-3G14-F threaded T-adapter, 3× G1/4 female (split to parallel valves + merge outputs). Each port needs a CK-1/4 fitting. | [Festo](https://www.festo.com/es/es/a/8030236/) |
| Buy | 4469 | 1 | LCK-1/8-PK-4 elbow, G1/8 → tube 6 mm (actuator connection) | [Festo](https://www.festo.com/es/es/a/4469/) |
| Buy | — | 1 | G1/4 female → G1/8 male adapter (actuator port) | TODO: find part number |

> **Note:** CK-1/4 qty increased from ~10 to ~15. The 6 extra fittings are for the NPFC-T threaded ports (3 ports × 2 T-adapters = 6 CK fittings).

> **Change:** TCK-1/4-PK-4 (4487) replaced by NPFC-T-3G14-F (8030236). The TCK was a push-in T-fitting; the NPFC-T is a threaded T-adapter that accepts CK compression fittings at each port, giving a more secure connection.

Datasheets (local):

- [`2029datasheet.pdf`](../../assets/datasheets/2029datasheet.pdf)
- [`4469datasheet.pdf`](../../assets/datasheets/4469datasheet.pdf)

## Silencers

On exhaust ports of all valves and the actuator exhaust.

| Status | Part No. | Qty | Description | Festo link |
|---|---|---|---|---|
| Buy | 2316 | 2 | U-1/4 silencer, G1/4 (EBS valve exhaust + VPPM exhaust) | [Festo](https://www.festo.com/es/es/a/2316/) |
| Buy | 2307 | 1 | U-1/8 silencer, G1/8 (actuator exhaust port) | [Festo](https://www.festo.com/es/es/a/2307/) |

Datasheet (local): [`2316datasheet.pdf`](../../assets/datasheets/2316datasheet.pdf)

## Cables & Connectors

| Status | Part No. | Qty | Description | Festo link |
|---|---|---|---|---|
| Buy | 542256 | 1 | NEBU-M12W8-K-2-N-LE8, M12 8-pin shielded cable (VPPM control) | [Festo](https://www.festo.com/es/es/a/542256/) |
| Check | 541333 | 2 | NEBU-M8G3-K-2.5-LE3, M8 3-pin cable (pressure sensors) | [Festo](https://www.festo.com/es/es/a/541333/) |
| Reuse | 8030810 | 1 | EBS valve coil **VACF-B-C1-5**, 12 V DC / 3.4 W, **connector form C** (EN 175301-803) | [Festo](https://www.festo.com/es/es/a/8030810/) |
| Buy | 151687 | 1 | MSSD-EB connector (**form C**) for the EBS coil | [Festo](https://www.festo.com/es/es/a/151687/) |
| Spare | 8030801 | 1 | ASB valve coil **VACF-B-B2-5**, 12 V DC / 3.4 W, **connector form B** (DIN, 11 mm). Only needed if the spare ASB valve is fitted | [Festo](https://www.festo.com/es/es/a/8030801/) |

> **Coil compatibility (12 V supply).** Both VUVS-LT25 coils are **electrically identical** — 12 V DC, 3.4 W (≈0.28 A), insulation class H, IP65 — so both run directly off the kart's 12 V rail and are interchangeable electrically. They are **not connector-interchangeable**, though: the EBS coil (VACF-B-C1-5, 8030810) is **form C** and mates with the MSSD-EB (151687); the spare ASB coil (VACF-B-B2-5, 8030801) is **form B** (11 mm DIN) and needs its own form-B plug — an MSSD-EB will not fit it. The validated circuit uses only the EBS coil + MSSD-EB, so this only matters if the spare ASB valve is ever wired in.

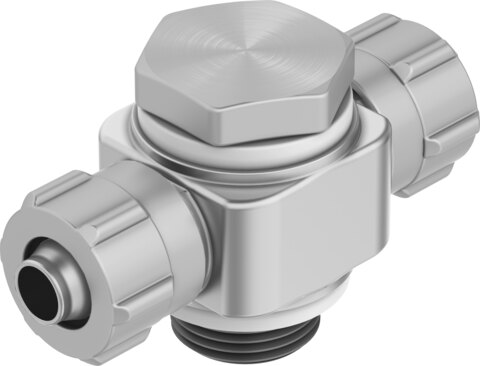
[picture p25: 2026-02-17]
docs/assembly/pneumatic-braking/images/components/festo-tck-1-4-pk-4.png

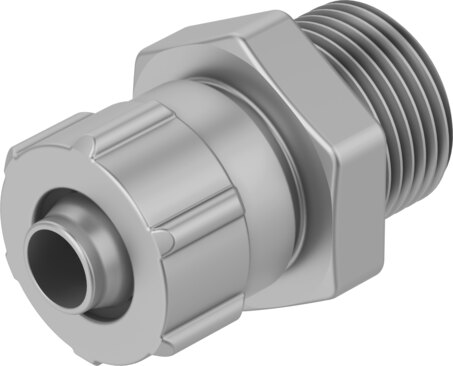
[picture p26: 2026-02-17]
docs/assembly/pneumatic-braking/images/components/festo-ck-1-4-pk-4.png

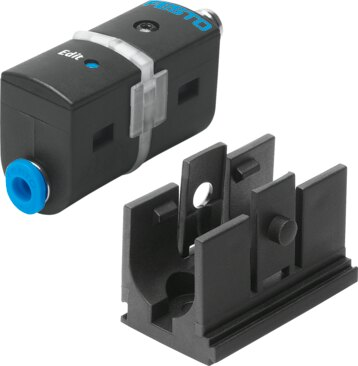
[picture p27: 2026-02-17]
docs/assembly/pneumatic-braking/images/components/festo-sde5.png

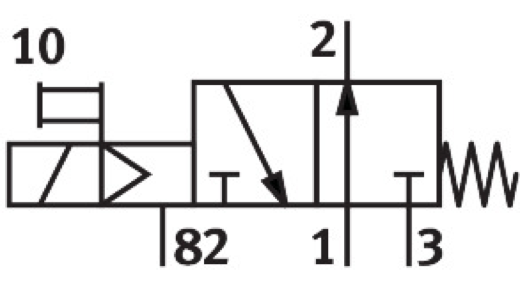
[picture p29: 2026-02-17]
docs/assembly/pneumatic-braking/images/components/festo-vuvs-symbol-large.png

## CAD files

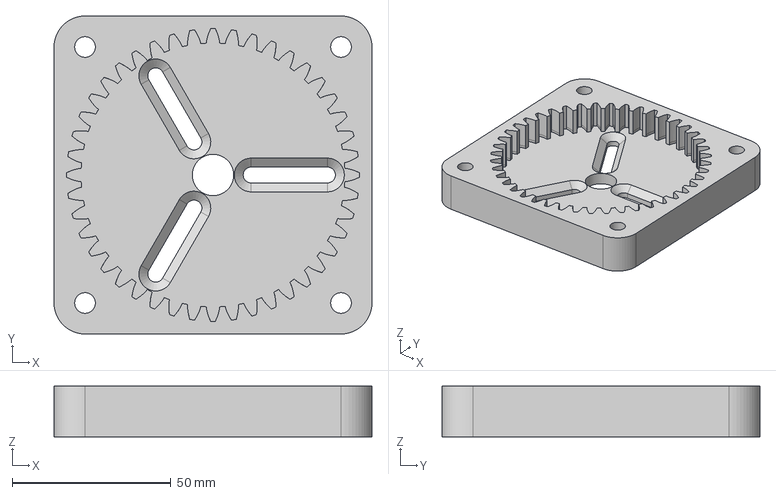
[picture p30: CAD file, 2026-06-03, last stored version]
docs/assembly/steering/cad/planetary-ring-gear.step
100.0 x 100.0 x 16.0 mm

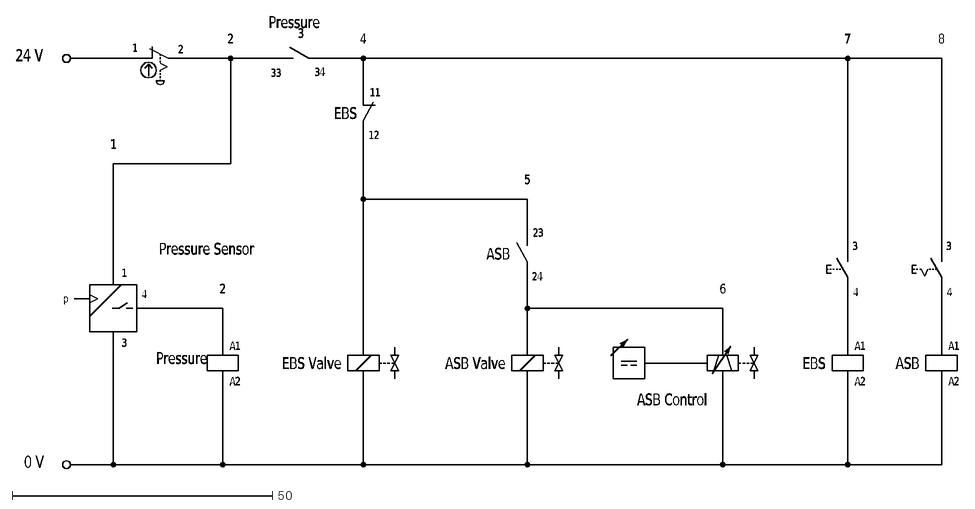
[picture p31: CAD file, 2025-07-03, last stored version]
docs/hardware/ebs/ASB_EBS_2.dxf
24 V
0 V
A2
A1
11
12
5
23
24
3
4
8
EBS
EBS Valve
ASB Valve
ASB
7
6
ASB Control
p
1
2
Pressure
33
34
Pressure Sensor

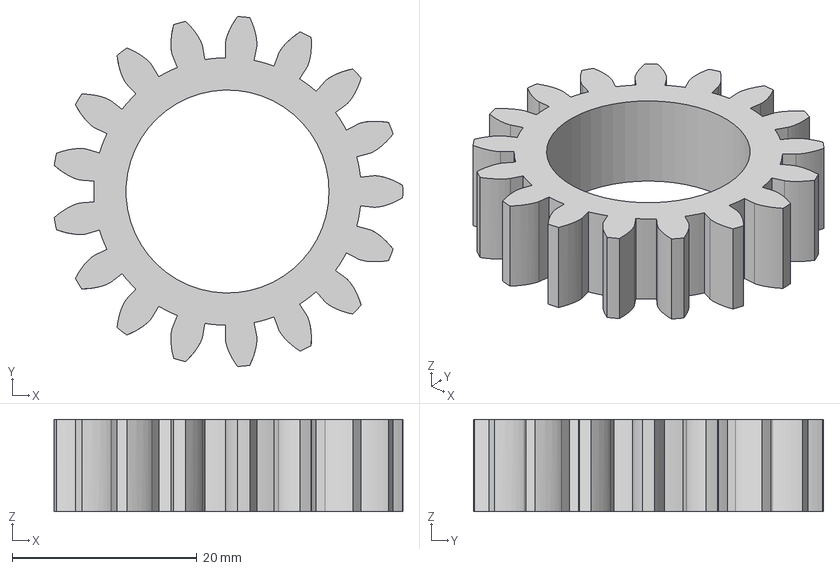
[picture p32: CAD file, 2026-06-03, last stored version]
docs/assembly/steering/cad/planetary-planet-gear.step
37.8 x 37.9 x 10.0 mm

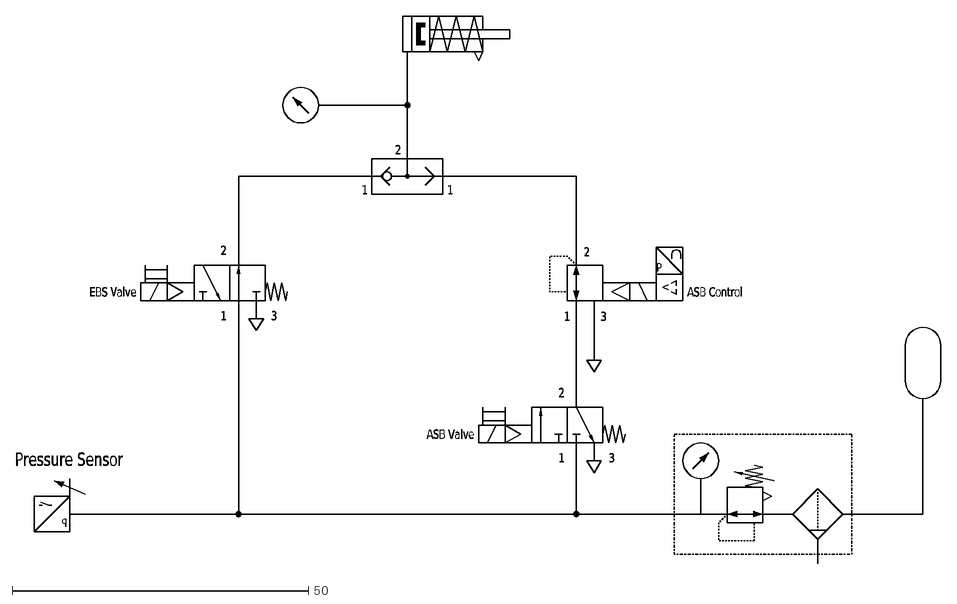
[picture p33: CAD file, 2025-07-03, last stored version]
docs/hardware/ebs/ASB_EBS.dxf
2
1
3
P
EBS Valve
ASB Valve
ASB Control
Pressure Sensor

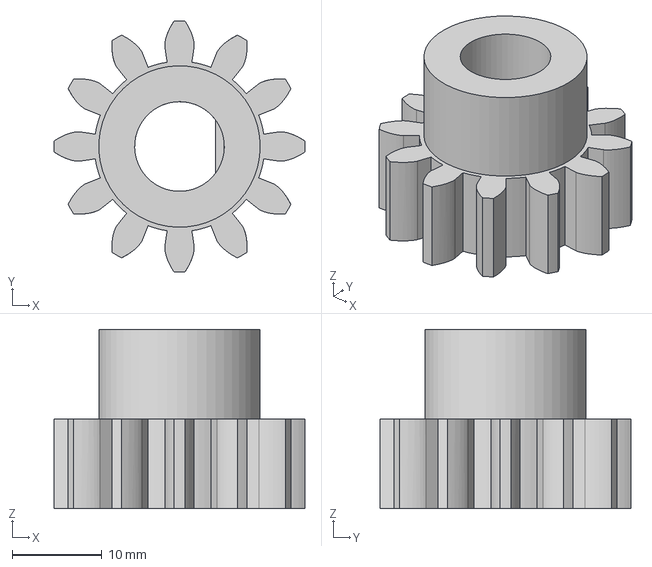
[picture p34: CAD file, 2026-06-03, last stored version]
docs/assembly/steering/cad/planetary-sun-gear.step
28.0 x 28.0 x 20.0 mm

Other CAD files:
docs/assembly/steering/cad/planetary-planet-gear.stl
docs/assembly/steering/cad/planetary-reducer.f3d
docs/assembly/steering/cad/planetary-ring-gear.stl
docs/assembly/steering/cad/planetary-sun-gear.stl

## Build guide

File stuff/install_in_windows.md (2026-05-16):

# Windows Installation Guide for kart-docs

This guide provides instructions for setting up the `kart-docs` project on a Windows machine.

## 1. Install uv

Install uv using PowerShell:

```powershell
powershell -ExecutionPolicy ByPass -c "irm https://astral.sh/uv/install.ps1 | iex"
```

After installation, restart your terminal for the `uv` command to be recognized.

## 2. Install Project Dependencies

Once uv is installed, install the project's dependencies:

```bash
uv sync
```

## 3. Install Headless Browser for PDF Export

To enable PDF export functionality, install a headless Chrome browser using Playwright:

```bash
uv run playwright install --force chrome
```

## 4. Previewing the Documentation

To preview the documentation locally:

```bash
uv run mkdocs serve
```

Then, open your web browser and navigate to `http://127.0.0.1:8000`.

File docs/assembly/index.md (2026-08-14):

# Assembly

This section contains all the information about the kart, organized as a tree of sub-assemblies. Each sub-assembly includes detailed specifications, components, and relevant documentation.

!!! note "Assembly Instructions"
    Step-by-step assembly instructions are still a work in progress.

## Hardware Overview

| Subsystem | Component | Key Specs | Details |
|---|---|---|---|
| **Chassis** | Tony Kart Extreme | CIK ICA 330/99, 30/32mm CrMo tubing, 40mm rear axle | [Chassis](chassis/index.md) |
| **Computer** | NVIDIA Jetson AGX Orin | 12-core ARM, 62 GB RAM, Ampere GPU (CUDA 12.6), NVMe boot | [Computer](electronics/computer.md), [Orin Setup](electronics/orin-setup.md) |
| **Camera** | ZED 2 stereo | USB 3.0, RGB + depth + IMU, used for cone detection | [Camera](sensors/camera.md) |
| **Microcontroller** | ESP32-S3 "Kart Medulla" | USB serial (CDC-ACM) to Orin, controls actuators | [Kart Medulla](electronics/kart-medulla/index.md) |
| **Steering** | DC motor + H-bridge | MT6701 magnetic angle sensor read as PWM, closed-loop PID on the ESP32 | [Steering](steering/index.md), [H-bridge](steering/h-bridge.md), [Angle Sensor](steering/sensor/index.md) |
| **Throttle** | MCP4922 SPI DAC → motor controller | 0–5 V analog signal | [Throttle Pedal](powertrain/throttle-pedal.md) |
| **Motor** | Electric kart motor | Controlled via motor controller + throttle signal | [Motor](powertrain/motor.md) |
| **Power** | Battery pack | Supplies 12V to Orin (via barrel jack 9–20V) + motor controller | [Battery](electronics/power/battery.md) |
| **Pneumatic braking** | ASB (proportional) + EBS (emergency) | VPPM + solenoid valve merged by an OR valve; EBS in shutdown circuit | [Pneumatic Braking](pneumatic-braking/index.md) |
| **Hydraulic braking** | Kart's original hydraulic circuit | M10×1.0 inverted-flare hoses, Sensata PTE7100 pressure sensor (0–200 bar) | [Hydraulics](hydraulics/index.md) |
| **Wiring** | Custom harness | Color-coded: black=GND, red=12V, orange=5V, yellow=3.3V | [Wiring](electronics/wiring.md), [Net Naming](electronics/net-naming.md) |

The two braking systems are not alternatives: the pneumatic side is what the autonomous stack and
the emergency circuit actuate, and it pushes on the kart's existing hydraulic brakes.

## Loose assembly notes

Things learned on the kart that have no better home yet. Move each one onto its subsystem page as
that page grows.

- The red plastic piece of the steering column goes on top of the bolt that holds it.
- The wheel bearings are separated by a spacer tube, so the bolts can be torqued down without
  putting a constant shear load on the bearings. **Its dimensions are not recorded** — measure the
  ID, OD and length off the kart and fill them in here.

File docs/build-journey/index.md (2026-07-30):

# Build Journey

Posts documenting the build of a competition kart turned autonomous vehicle. Roughly one a week. New posts append at the bottom — read straight through.

[Follow on LinkedIn :fontawesome-brands-linkedin:](https://www.linkedin.com/in/rubenayla/){ .md-button }

**Jump to:** [Intro](#intro) · [Motor](#motor) · [AI Inventory](#inventory-ai) · [Battery](#battery) · [Why 48V](#why-48v) · [Roll hoop](#main-hoop) · [First drive](#first-drive) · [Steering](#steering-actuator) · [Planetary reducer](#planetary-reducer) · [Reducer build](#planetary-build) · [Steering control](#steering-control) · [Dashboard](#dashboard) · [Autonomous drive](#autonomous) · [The PCB](#pcb) · [AS5600 magnet](#as5600-magnet)

---

## Turning a kart into a driverless racing car { #intro }

*2026-04-22*

We're turning a kart into a driverless racing car.

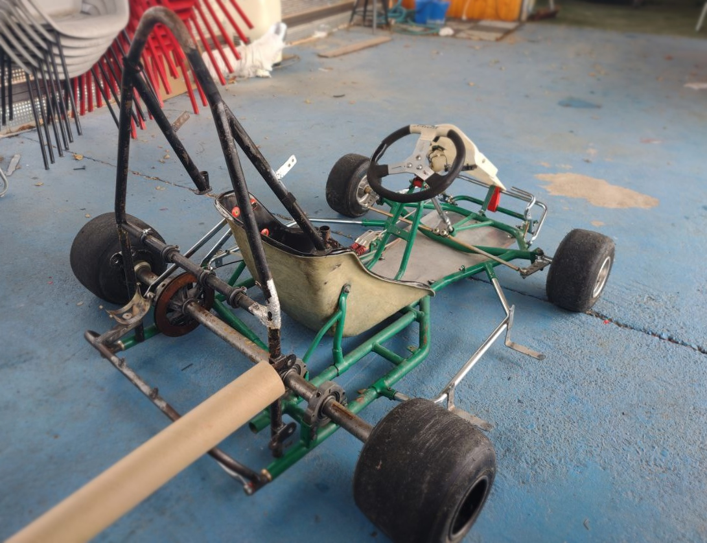
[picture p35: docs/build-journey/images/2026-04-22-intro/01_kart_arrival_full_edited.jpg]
Kart arrival


Huge thanks to Henakart. They gave us the whole kart, minus the engine. The rest is on us: the full autonomous stack. I'm on Ü Motorsport Driverless, the URJC student team in Madrid.

I'll post the build from day one, one piece every Wednesday, until the kart's lapping with no one in the seat.

Three stages:

1. Make it electric, so it moves under its own power.
2. Make it remote-controlled, and safe.
3. Make it driverless, so it drives itself around a cone track.

Coming up: motor → battery → braking → steering → compute → testing.

Everything's going into these [kart docs](../index.md) so anyone can build it themselves.

---

## Mounting the motor, and why the first bracket failed { #motor }

*2026-04-29*

For our kart, the first step is to attach the motor. We kept it simple: a 48V 2000W BLDC kit, which included the controller, throttle sensor, and wiring. Our engineering goes into the battery, the safety system, and the autonomy stack.

Mounting it to a Tony Kart frame was a different job.

The first bracket was PLA, printed on a Bambu Lab. It bolted to the kart's tube frame and held the motor leveled with the rear axle. The bolt holes let us slide the motor to set chain tension. The kart ran on it for months.

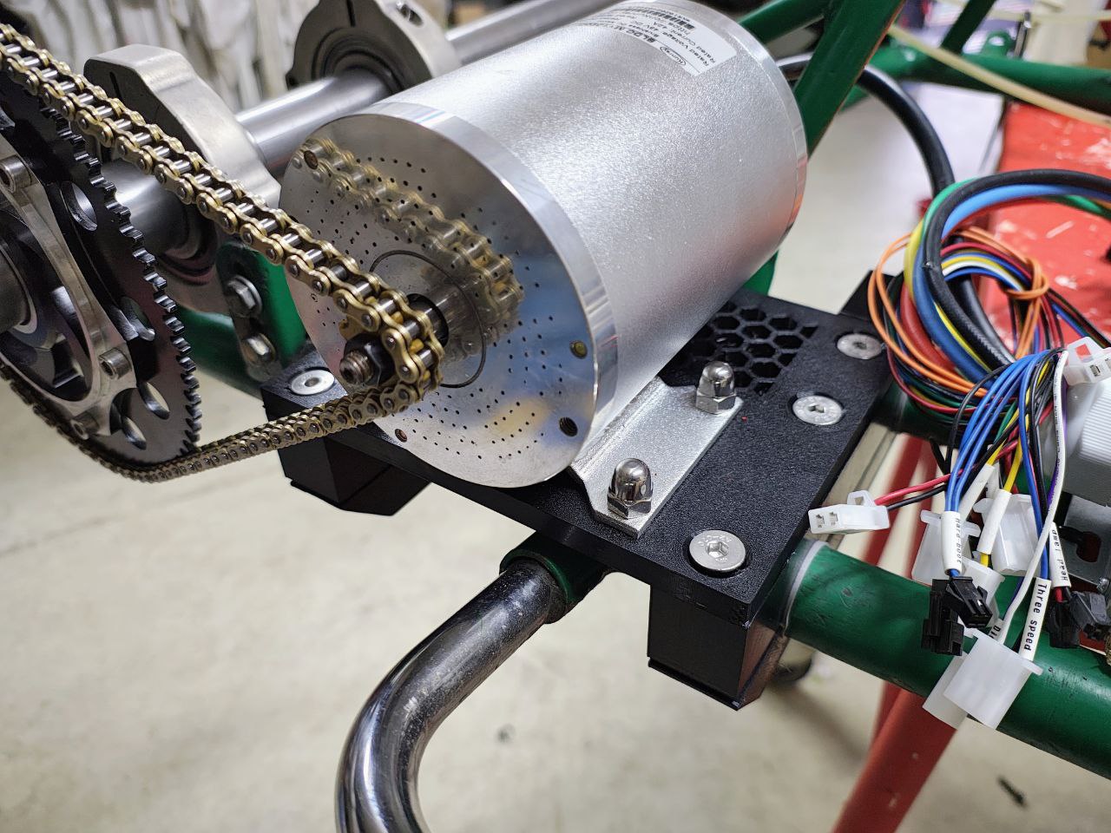
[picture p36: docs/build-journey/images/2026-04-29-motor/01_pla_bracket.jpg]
PLA bracket, first version


Then it failed in a specific way. The bolt nuts were embedded inside the print, hex pockets buried in the plastic. The nuts were nylon-locking. Tightening the bolts meant fighting the nylon insert's friction, which took enough torque to crack the pocket walls from the inside. The nuts started spinning instead of gripping, the bolts went loose, and we couldn't retighten them because the nuts were buried inside a part we'd have had to destroy to reach them.

Standing in the workshop thinking about the replacement, we asked a better question. Why are we holding the motor horizontally to the sprocket, elevated from the chassis? There's no real reason. We can place the motor on the chassis itself, with a flat welded steel plate. And we can do that ourselves, without waiting for orders.

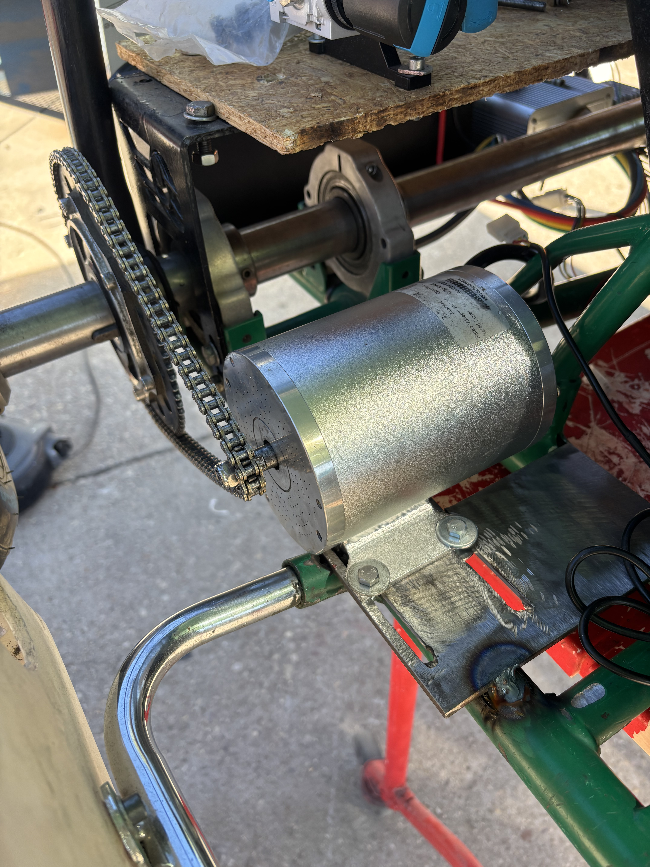
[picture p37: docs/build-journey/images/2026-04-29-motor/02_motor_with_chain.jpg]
Motor mounted to the welded steel plate, with chain


We considered fancier options. A grid of shifted holes for positive locking. A tensioner bolt in the style of combustion-engine karts. The slot won because it's the simplest approach, and we could always add a tensioner if the slot ever started moving — but it didn't happen.

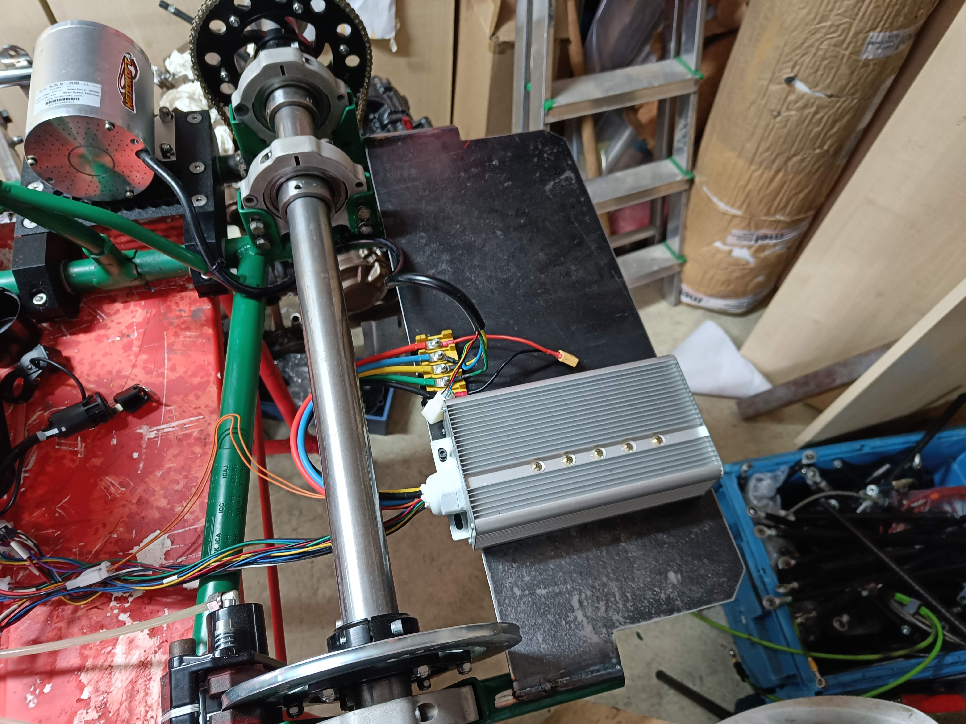
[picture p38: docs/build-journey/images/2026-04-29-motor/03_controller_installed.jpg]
Motor controller installed


The kit also shipped with a chain in a different pitch than the kart's: T8F (8 mm) versus #219 (7.774 mm). The two look almost identical. We standardized on #219 and laser-cut a custom pinion to fit the motor's D-shaped shaft.

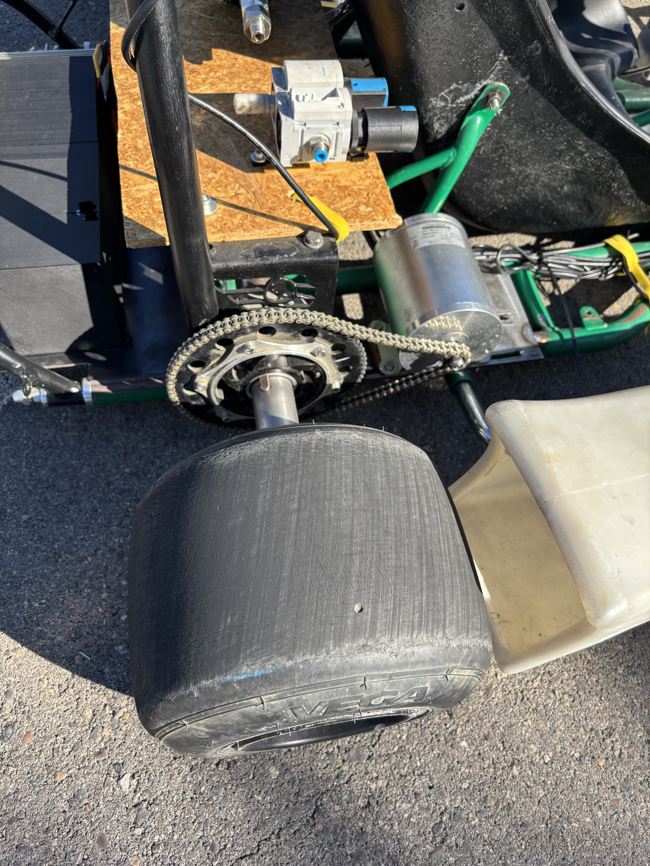
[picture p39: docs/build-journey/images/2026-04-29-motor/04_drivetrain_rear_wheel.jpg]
Drivetrain at the rear wheel


Months later, the question "wait, which pitch did we use?" kept coming up. That's why everything goes into these docs.

---

## Using an AI Inventory to design PCBs { #inventory-ai }

*2026-05-04*

We're using an AI Inventory to design PCBs.

"Do we have any DAC chips in stock?" If answering that means going on a trip to the workshop and spending an hour looking for them between bags, we're doing something wrong.

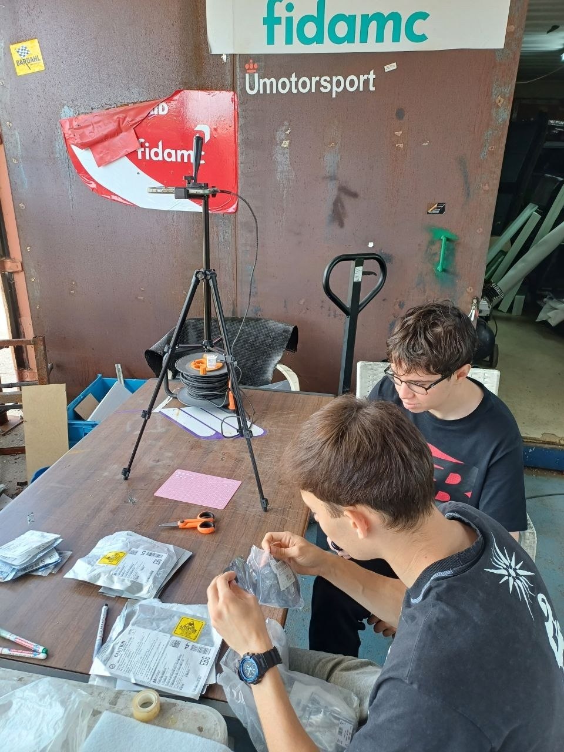
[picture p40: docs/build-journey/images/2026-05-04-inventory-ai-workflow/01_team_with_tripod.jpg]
The team photographing components on a tripod rig


Nobody wants to do an inventory, so we made it as easy as possible. We set up a tripod over a workshop table, and took pictures of all 270 bags with components.

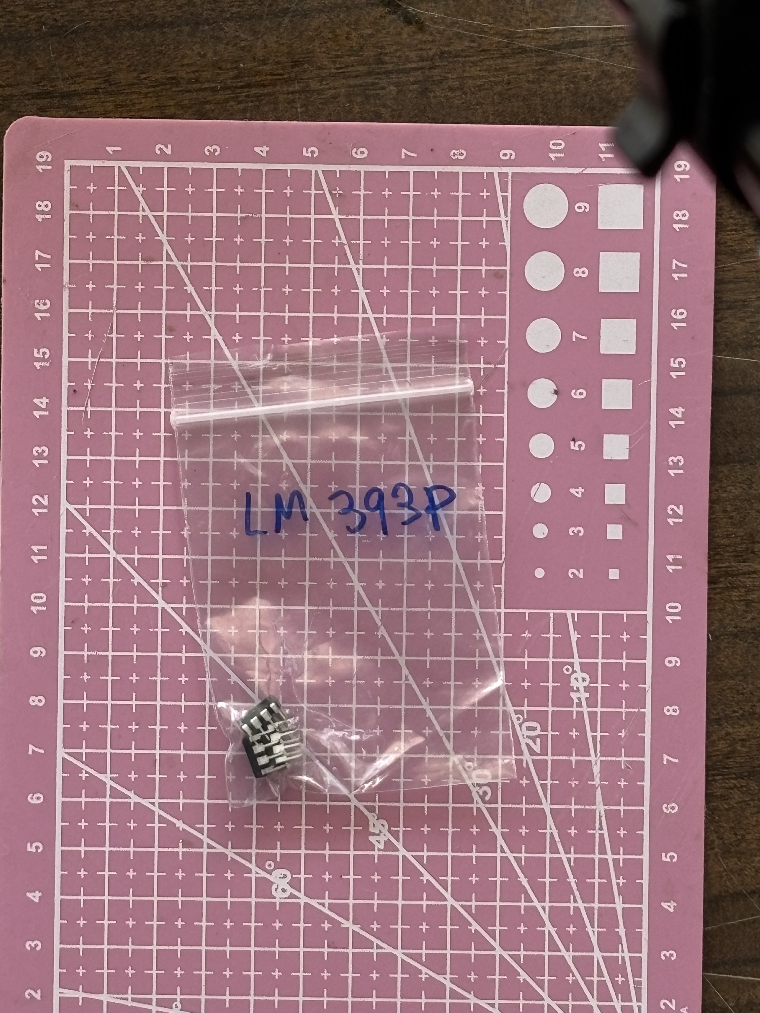
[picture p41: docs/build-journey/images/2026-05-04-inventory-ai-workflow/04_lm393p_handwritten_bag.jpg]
Handwritten LM393P component bag


Then, Claude identified each component, looked the manufacturer part number up online for description and datasheet, and saved the data into [Notion](https://www.notion.so/) using their MCP connector. It worked at first try.

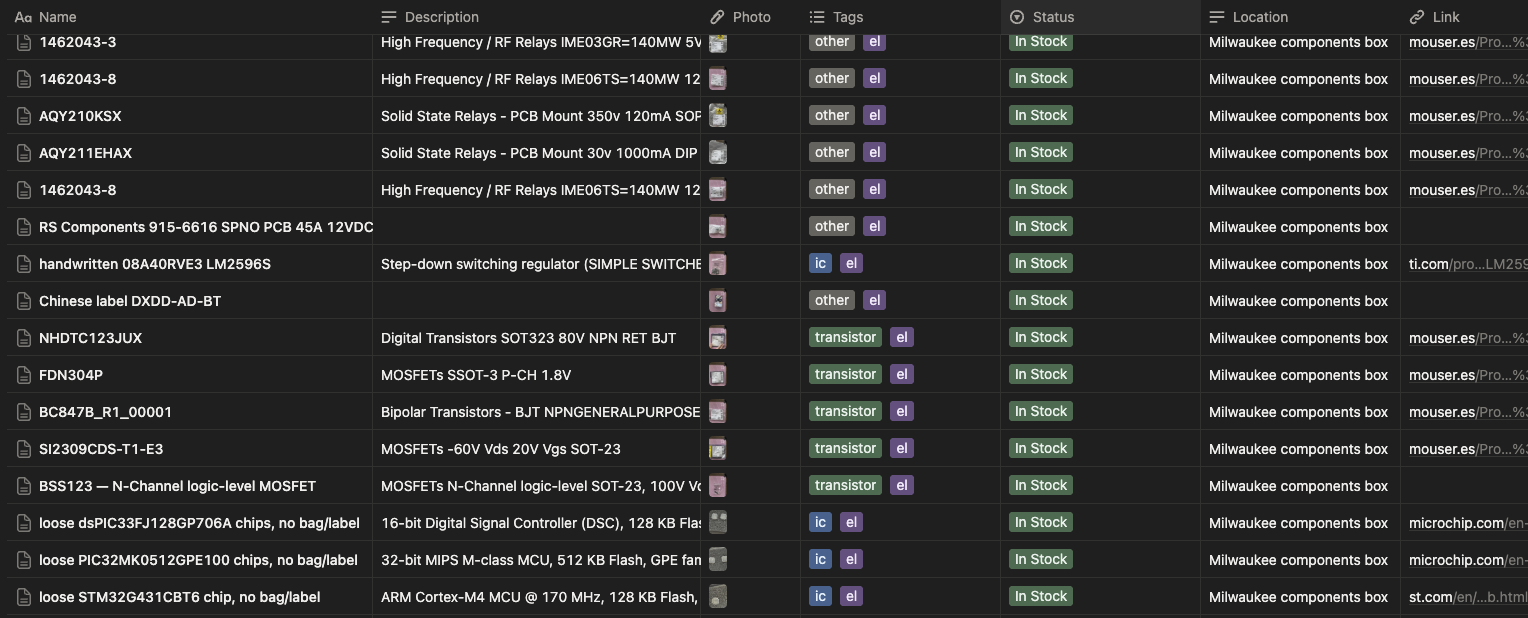
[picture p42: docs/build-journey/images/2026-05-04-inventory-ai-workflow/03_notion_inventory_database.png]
Notion inventory database


Now we can ask things like:

> "Hey Claude, we need to generate two analog signals from an ESP32 — one 0–5V, one 0–10V. What can we use from the inventory?"

And get back:

> "Use the DAC7574 (quad 12-bit I²C, 2 in stock). With VREF = 5V, the first channel gives 0–5V directly. For the 0–10V channel, route the second channel through an LM358 wired non-inverting at gain 2 (R1 = R2 = 10 kΩ, both in stock). Power the op-amp from the kart's 12V rail. Heads up: you're down to 2 DAC7574s. Probably worth adding a few to the next Mouser order."

<div style="max-width: 315px; margin: 1em auto;">
  <div style="position: relative; padding-bottom: 177.78%; height: 0;">
    <iframe
      src="https://www.youtube.com/embed/xWUMcP6Wm6w"
      title="Our Inventory is AI — Formula Student kart"
      frameborder="0"
      loading="lazy"
      allow="accelerometer; clipboard-write; encrypted-media; gyroscope; picture-in-picture"
      allowfullscreen
      style="position: absolute; top: 0; left: 0; width: 100%; height: 100%;"></iframe>
  </div>
</div>

Huge thanks to Gabriel Fernández Romero and Adrián for the help.

If you have a similar workflow, try this and share your experience — I'm loving it so far.

---

## Building the battery pack from bare cells { #battery }

*2026-05-14*

We made the battery pack ourselves. Why?

To practice. And because we had a bunch of cells lying around from a past project that never used them: 60 Molicel P42A 21700 cells, bought for an electric-vehicle experiment that never happened.

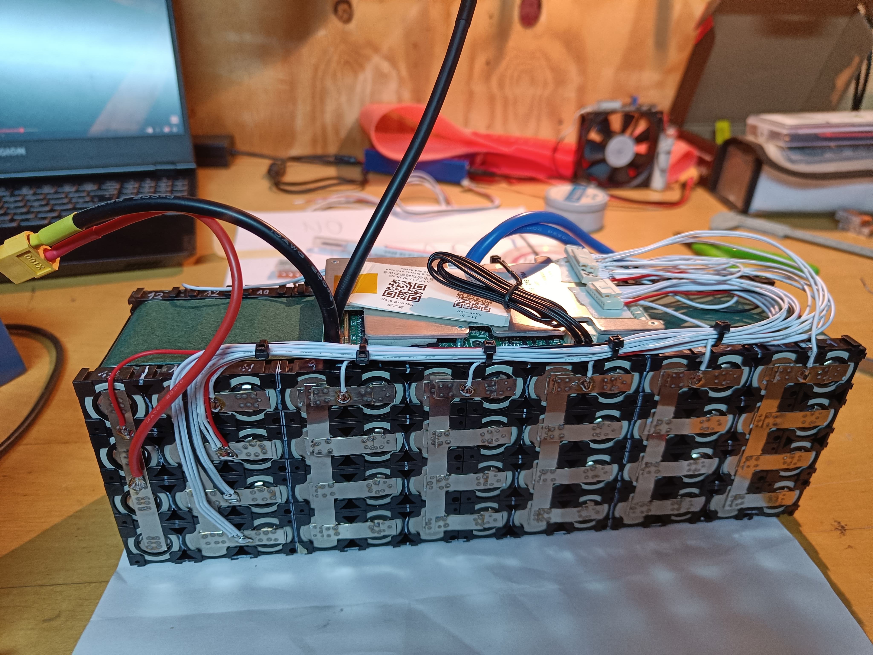
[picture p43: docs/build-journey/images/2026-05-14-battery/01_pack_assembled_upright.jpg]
The finished 13S battery pack


We needed roughly 48V, so 13 cells in series, 46.8V nominal. The motor draws around 2 kW continuous, so the pack could deliver close to five times what the kart actually asks for. It's the first pack we've ever built, so we wanted big safe margins and no power issues for the computer.

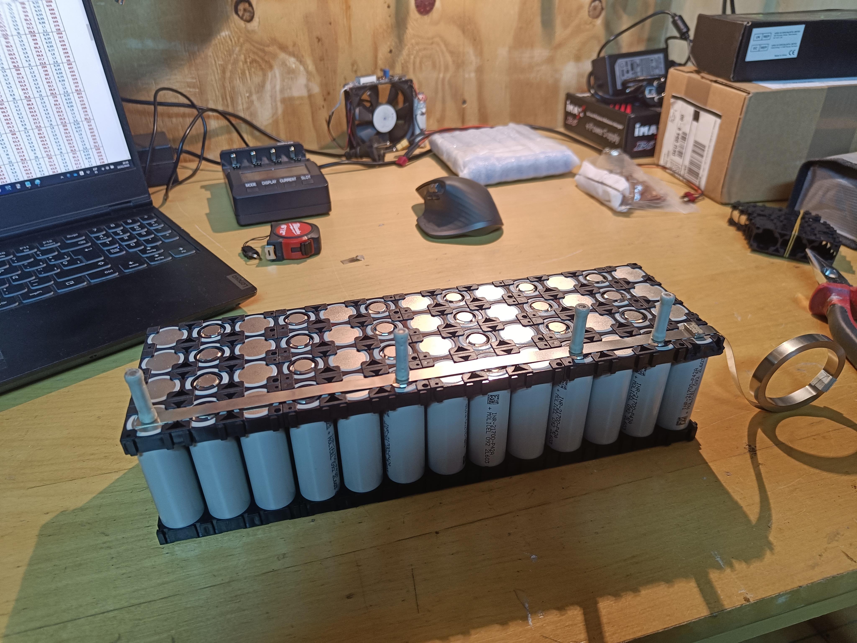
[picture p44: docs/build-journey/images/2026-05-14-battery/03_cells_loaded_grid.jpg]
Molicel P42A cells loaded into the holder grid


We connected the cells with classic nickel strips. All the current actually flows through the series connections between groups, so the first strip goes in series, then a parallel strip, then another series strip. That's 8 strips per series link sharing the load. At 43 A continuous that's about 5 A per strip. Plenty of margin, and even at the per-cell limit of 45 A each strip stays inside its burst range.

We did the welding with a kWeld. It's funny how it pulses so much current that the magnetic field between its two leads shoves them sideways.

<div style="max-width: 280px; margin: 1em auto;">
  <video controls playsinline preload="metadata" style="width: 100%; border-radius: 8px;">
    <source src="videos/battery-spot-weld.mp4" type="video/mp4">
  </video>
</div>

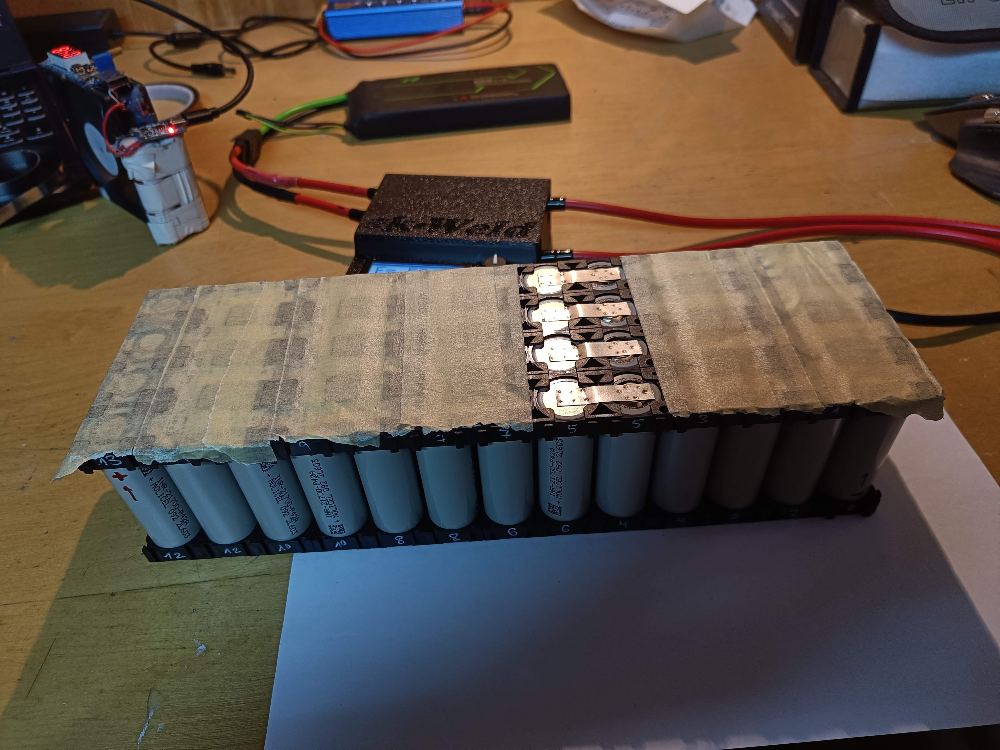
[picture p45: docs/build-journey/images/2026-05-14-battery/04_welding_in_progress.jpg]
Welding nickel strips between the cells


For monitoring, a JBD (Jiabaida) smart BMS with Bluetooth, so we can watch every cell's voltage and state of charge. The Bluetooth advertises continuously waiting for a phone to pair, which we assumed would slowly drain the pack, but after months sitting idle the voltage barely moved.

The pack lives inside a 3D-printed shell with fireproof expanding foam packed around the cells. We drilled two holes, one for the nozzle and another to vent the displaced air, but didn't have the proper applicator gun. The photo below is the result of using pliers to push the bottle open. It was a mess, but it worked. We learned that waiting to do things "properly" can make you wait forever; sometimes you just do it with what you have. Counterintuitively, aiming for fast progress catches errors earlier and makes the end result higher quality.

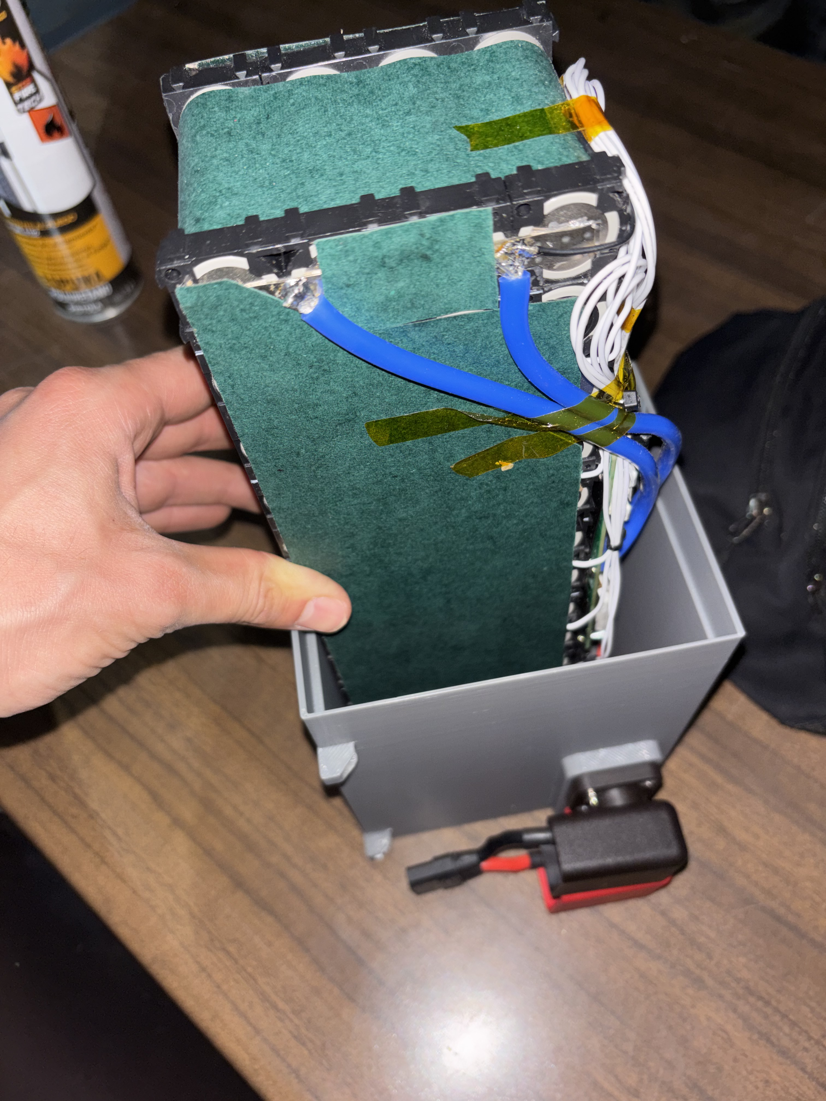
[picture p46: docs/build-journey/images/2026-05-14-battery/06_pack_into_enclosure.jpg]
Lowering the pack into its 3D-printed enclosure


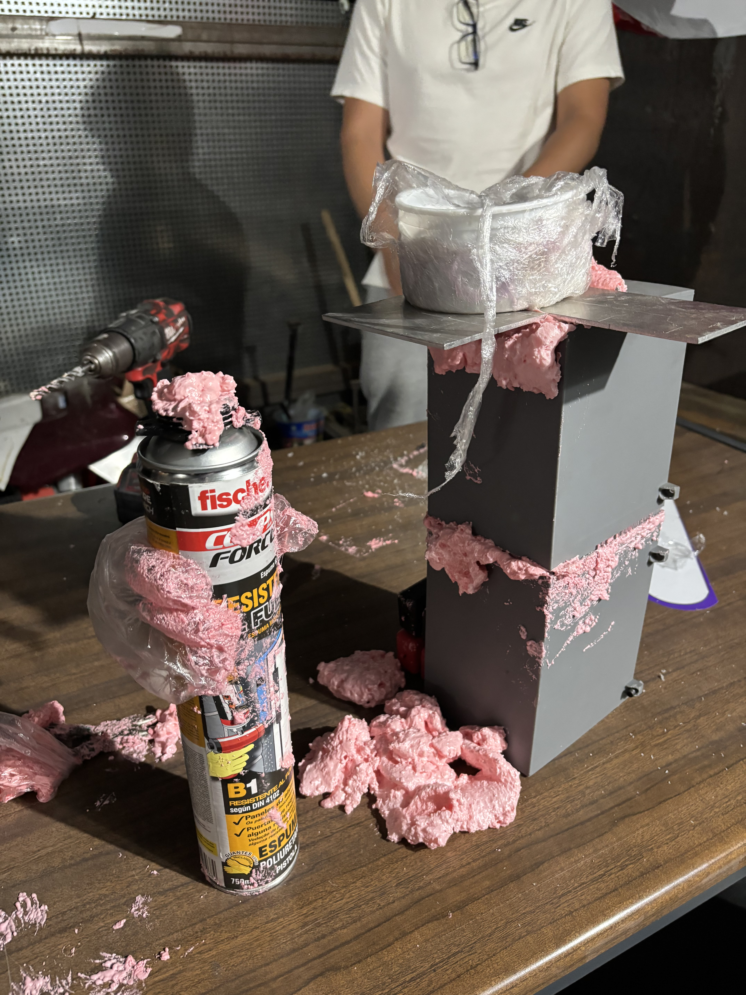
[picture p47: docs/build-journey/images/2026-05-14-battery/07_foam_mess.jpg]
Expanding foam, applied with pliers instead of a proper gun


The whole thing took over 10 hours of work: cells in holders, several layers of nickel strips welded between them, 13 BMS wires soldered and routed cleanly, kapton tape and fish paper so nothing shorts, the printed box, the foam, the cure, plus all the planning and buying the right components. Now I understand why packs cost so much more than just the cells. The amount of time it takes is ridiculous.

But we got a fantastic pack in the end. We can drive as hard as we can, continuously, and the internal temperature never rises more than 10°C above ambient.

It's interesting to think about how we'd build this at scale. The process would have to be entirely different: CNC machines doing the spot welding, pre-made connectors with the layout, maybe a dedicated channel in the cell holders to route the wires through with a jig to place them easily. Automating the BMS-wire soldering would be awkward.

---

## Why 48V, and not more { #why-48v }

*2026-05-18*

A common question is: why 48V for the kart battery?

There are two reasonable battery voltages for our kart: under 50V, or several hundred volts. The middle doesn't make sense.

What hurts you is the current through nerves and the heart. Voltage is what drives that current, and your body's resistance to it isn't constant. Skin is mostly capacitive, so it lets AC through more easily than DC, because alternating current keeps charging and discharging the outer layer and leaking into the nerves underneath.

The resistance of skin drops when you raise the voltage, as it starts breaking down, so doubling the voltage doesn't make it twice as dangerous: it causes roughly 3x the current and the safe exposure time drops an order of magnitude. Around 10 mA your muscles lock around the wire and you can't let go. Around 50 mA your heart fibrillates.

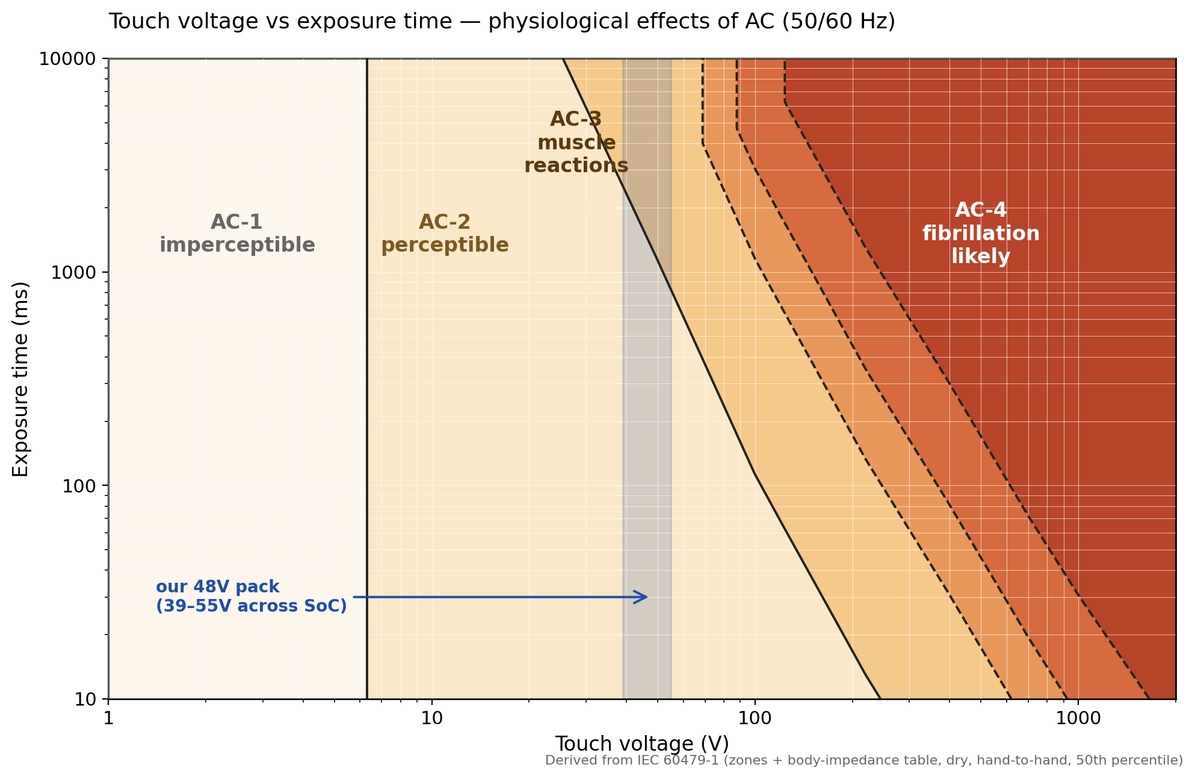
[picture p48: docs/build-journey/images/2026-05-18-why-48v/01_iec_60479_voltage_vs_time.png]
Touch voltage vs exposure time, from IEC 60479-1. Our 48V pack sits at the edge of the perceptible zone.


There's no clean threshold, but in the 40–60V range the risk rises very fast, from negligible to significant.

So our pack lands at 13 cells in series, near the highest that can be touched without worry. Anything higher and we'd be building a high-voltage kart: isolation, interlocks, insulated tools, training for anyone who touches it.

---

## A roll hoop, a bearing spacer, and a throttle sensor { #main-hoop }

*2026-05-21*

Karts don't come with roll hoops. They sit low, weigh little, and drivers don't wear seatbelts. In a flip, an unbelted driver gets thrown clear: the kart slides on, the driver lands and tumbles. A hoop bolted overhead turns that into a cage you can't be ejected from, and a kart you can be pinned under. So competition karts ride open.

In our driverless kart we want to be as close to a Formula Student car as possible, and FS cars have seatbelts and roll hoops. On top of that, we needed a high, rigid spot for the stereo camera, which a roll hoop gives us.

We reused the main hoop from a past season's FS car. Its tube ends were round, but bolts need a flat surface to clamp against. We heated the ends with an oxy-propane torch until red, pressed them flat in a hydraulic press, drilled the bolt holes, and bolted the hoop down. It still needs a support bar across the top to stiffen it. That's the next job.

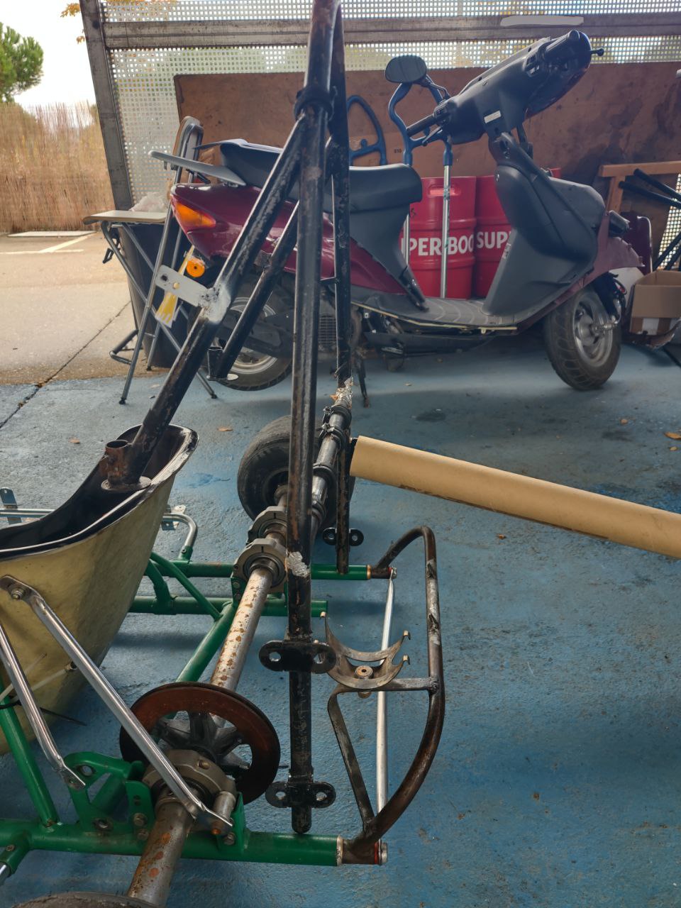
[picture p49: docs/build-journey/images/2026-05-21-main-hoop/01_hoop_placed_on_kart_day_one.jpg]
The reused FS roll hoop placed on the kart


Thanks to our friends at RB Sistemas for helping with this part.

Next are the wheel bearings. Each wheel has two, one on each side of the rim, with the axle through both. We torqued the axle nut and the wheel didn't spin freely: without a spacer between the inner races, the clamp force could only travel through the bearings themselves. So we cut a tube to length as a spacer and installed it, so the inner races are pressed against the spacer by the nut. Now the bearing only has to take the lateral loads of the kart turning.

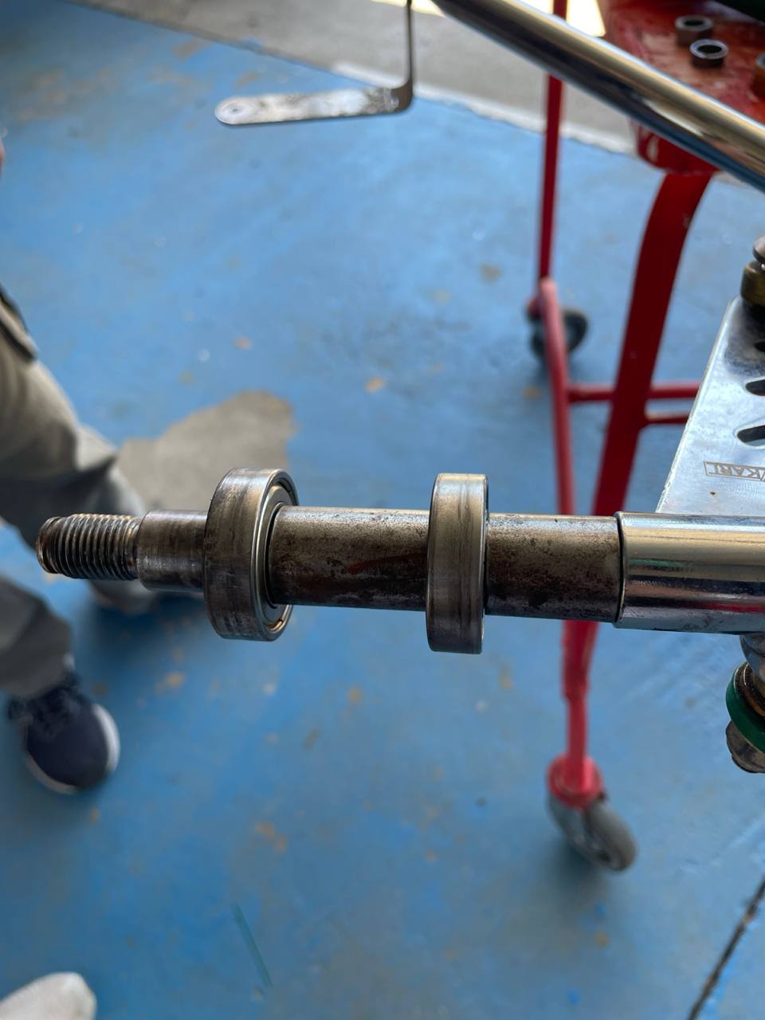
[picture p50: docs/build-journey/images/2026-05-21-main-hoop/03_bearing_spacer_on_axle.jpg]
The spacer on the axle, between the inner bearing races


The kart already had its own accelerator pedal. We needed a sensor on it to read its position, so we took the hall sensor that came with the motor kit and installed it on our pedal with a threaded rod to the chassis. It reads the strength of a magnet and outputs an analog voltage between 0 and 5V.

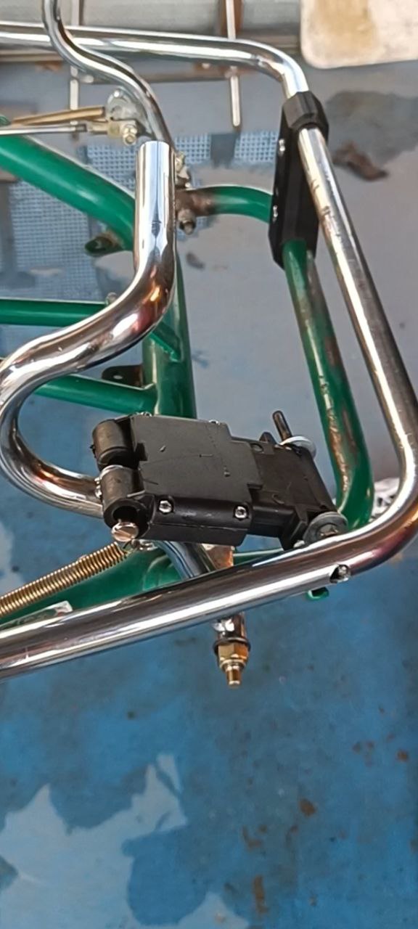
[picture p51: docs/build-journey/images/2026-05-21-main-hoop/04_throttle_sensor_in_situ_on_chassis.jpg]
The hall throttle sensor mounted on the pedal


Next: the first manual drive.

---

## The first manual drive { #first-drive }

*2026-05-27*

Finally, the kart works.

<div style="max-width: 315px; margin: 1em auto;">
  <video controls playsinline preload="metadata" style="width: 100%; border-radius: 8px;">
    <source src="videos/first-manual-drive.mp4" type="video/mp4">
  </video>
</div>

On one of the first runs, the motor pinion gave out. It was a 3D-printed plastic placeholder; we'd been waiting months for the proper machined metal one. The D-profile on the bore rounded off against the motor shaft. The actual cause was the nut backing off, letting the pinion wobble. We swapped in a left-handed nylon locking nut instead of the one that came with the kit, and that fixed it.

We have a kart that moves. Next step is to make it remote-controlled.

In parallel, we're working on the code. There's a [legacy Python codebase](https://github.com/UM-Driverless/driverless) with multithreading from before LLMs were a thing, and the plan is to rewrite it in ROS 2.

---

## Making the kart steer itself: the actuator search { #steering-actuator }

*2026-06-10*

Here we are, with a completely manual kart, and we have to make it turn itself.

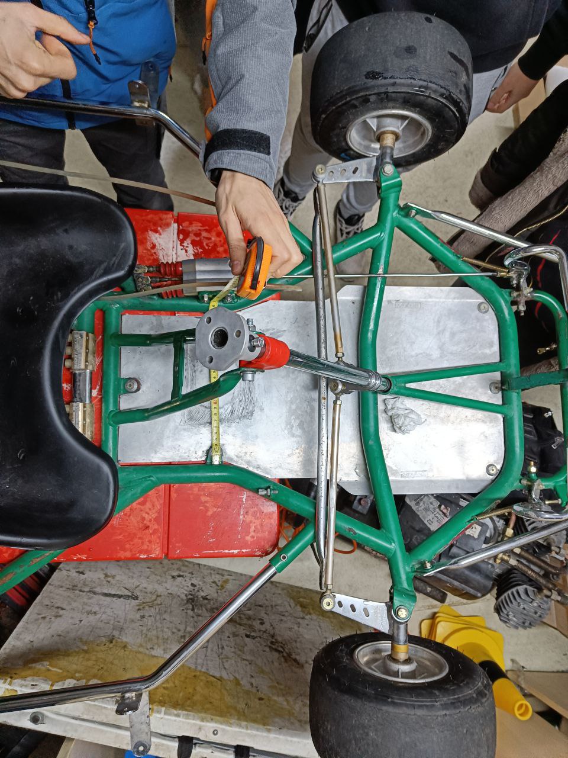
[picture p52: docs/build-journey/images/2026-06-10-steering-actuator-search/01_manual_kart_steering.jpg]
The kart's manual steering column


The idea is simple: put an actuator on the steering column to turn it.

But you can't imagine how hard it was to find components for that. Some companies make custom actuators, but we didn't find simple off-the-shelf solutions. They're either too weak, designed for a street car, or built for industrial applications: huge, heavy, and expensive.

For reference, we need about 8 Nm of torque at the steering column to fully turn the wheels while the kart is stopped and loaded with a driver, on grippy floor, which is the worst case. We set a maximum of 0.15 seconds to move the wheels side to side (50 degrees). That's about 6 rad/s, so P = τ·ω = 8 Nm × 6 rad/s ≈ 47W.

There are two main ways to turn it:

1. A rotary system, where you put a gear on the steering column and another on the servo, and that transfers the turning motion.
2. A linear system, where the actuator moves linearly and acts on a lever that turns the steering column.

Linear actuators can provide a lot of force in a compact way, but they can't be backdriven (they lock up), so the kart can't be ridden manually with one unless you use ball screws, which are expensive. On top of that they're slow. You get a lot of reduction, but watt for watt they can't deliver that much mechanical power, and the movement ends up too slow to compensate.

Think about it intuitively: power = torque × angular velocity (P = τ·ω). We can get the same power with a lot of torque or a lot of angular speed.

The torque a motor applies comes from the current flowing through it, which also heats the coils. The coils have a maximum temperature they can withstand, so cooling capacity limits torque directly. For speed, the limits are the mechanical strength of the rotor (so it doesn't explode) and the back-EMF it generates by turning fast. To hit those limits the motor has to spin really fast.

So if we want a lot of power from a small motor, we make it spin fast and gear it down for the torque we need. That's why we went with a rotary actuator.

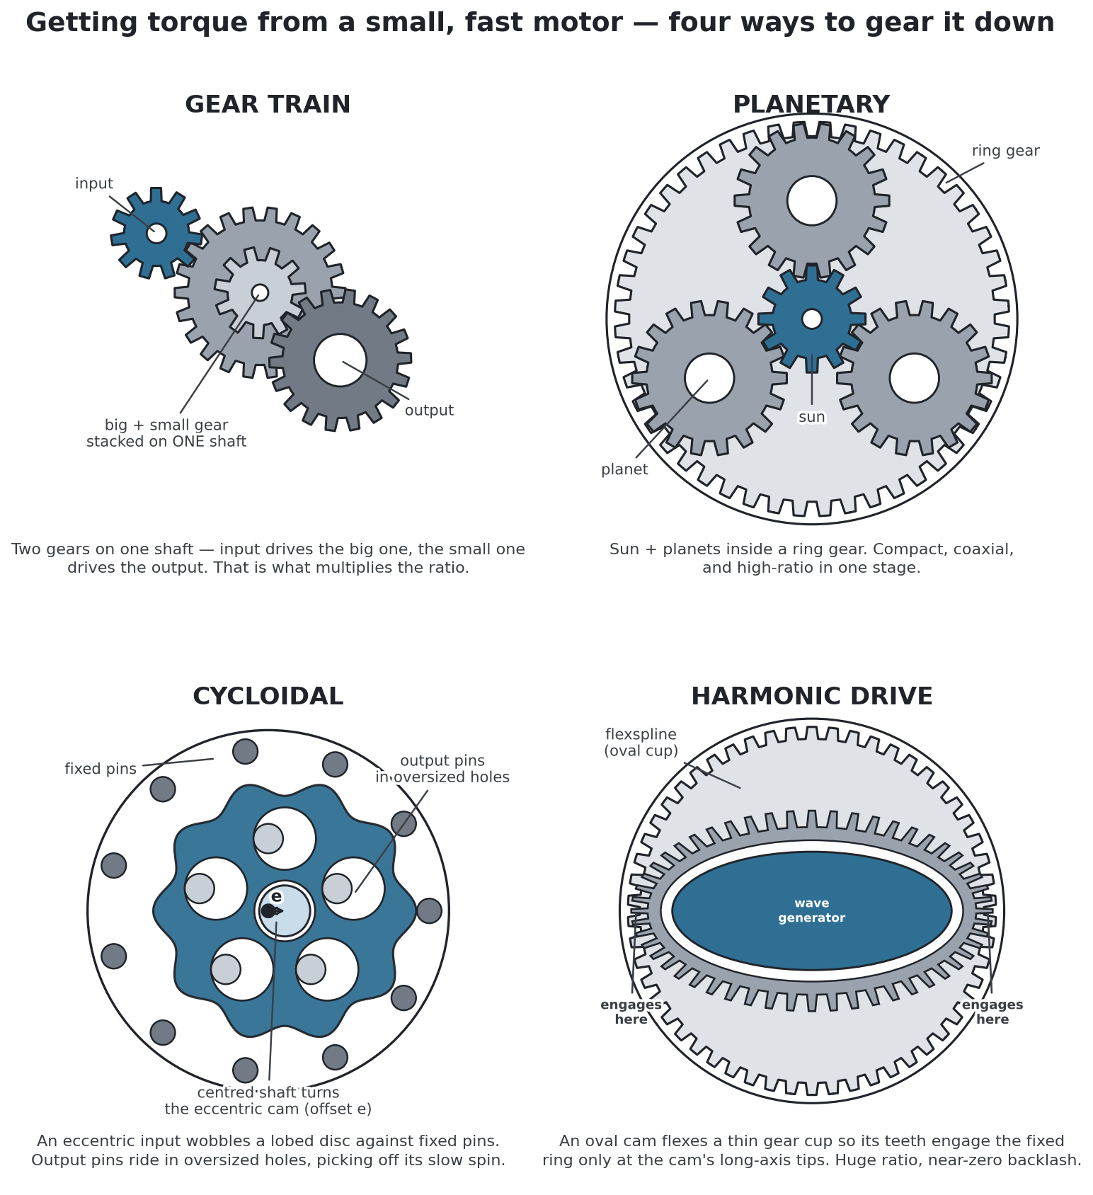
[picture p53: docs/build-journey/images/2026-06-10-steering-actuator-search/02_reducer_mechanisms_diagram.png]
Four ways to gear a fast motor down: gear train, planetary, cycloidal, harmonic drive


How would you gear it down? Anything from the diagram above, or something else?

Steering system docs: [Assembly → Steering](../assembly/steering/index.md).

---

## Why a planetary reducer { #planetary-reducer }

*2026-06-29*

Last time we talked about the decision to make our own actuator. Why a planetary reducer, of all things?

A belt needs a tensioner. A worm or a screw won't backdrive, so the wheels lock if the power dies. A harmonic drive needs a steel flexspline you can't just print if you want any strength.

We could use a plain gear train between the motor and the steering column, using both shafts. The disadvantage is the added slack.

A cycloidal drive could also work, but it's more complex and needs specific components we'd have to order, which would delay the project, especially while we still don't know the details of this little subsystem. It's a good alternative, and we're not discarding it, but for now we go with the (somewhat) simpler planetary reducer.

For us, the fastest way to get a prototype working is to 3D-print the planetary reducer to match a motor we already have. That motor comes from an old massage chair.

<video controls playsinline muted preload="metadata" style="width: 100%; max-width: 720px; display: block; margin: 1em auto; border-radius: 8px;">
  <source src="videos/planetary-cad.mp4" type="video/mp4">
</video>

Our first prints stripped out under the steering loads. A tougher filament would probably hold, but a spool of it costs more than just buying the gear. So we stopped printing and adjusted the design to use a standard steel gear from Norelem.

Next week we'll talk about the exact design.

Steering/planetary docs: [Assembly → Steering](../assembly/steering/index.md).

---

## The reducer, built { #planetary-build }

*2026-07-01*

Last post we chose a 3d printed planetary reducer to fit the motor we already had. We redesigned it a few times before it held up on the kart.

We used a laser-cut steel bracket tig-welded to the chassis. The motor face has threaded holes, so it bolts straight to the reducer casing with the steel bracket sandwiched between.

The first holder deformed under the load so much that the big gears started skipping teeth. We redesigned it so the lid holds a bearing and makes the distance between the gears constant. Also did smaller fixes like adding a cover so the planets don't get stuck on inner bolt heads, and playing with tolerances. The video doesn't include these fixes yet.

<video controls playsinline preload="metadata" style="width: 100%; max-width: 340px; display: block; margin: 1em auto; border-radius: 8px;">
  <source src="videos/steering-planetary-built.mp4" type="video/mp4">
</video>

All this work let us find the real bottleneck: the D-flat coupling of the sun gear with the motor shaft strips out. PLA, ABS, and Nylon all break.

We redesigned it to use a standard steel gear from Norelem, and did some tests by limiting the PWM to about 40% in the meantime.

Now we have a reducer that turns the steering column when we power the motor. Next we have to control the angle precisely. We're basically building a servo.

Steering/planetary docs: [Assembly → Steering](../assembly/steering/index.md).

---

## Making the steering hold an angle { #steering-control }

*2026-07-03*

Plug a battery straight into the steering motor and the steering just swings hard to one side. We need it to stop at the exact angle the software asks for instead.

For that, we obviously need a way to know where the steering is pointing, and a way to control the power we apply. Then some brains will decide how much power we need to reach the angle we want.

We sense the angle with an amazingly cheap and effective chip: a Hall-effect angle sensor (an AS5600, about €3). If you put a magnet nearby, it tells you the angle of the magnetic field. The magnet can move around in space and the sensor still picks up the angle, as long as it's close by.

To control the power of the motor you need to control the current. This paragraph goes into unnecessary detail about it, just so we understand from first principles why it's done the way it is.

If you wanted to apply just a little bit of power (a small current), you'd need to somehow stop the electrons of the battery from flowing to the motor. The obvious way is with a resistor in series, which limits the current and makes the motor's voltage drop smaller.

The problem is that it wastes energy. The only way to prevent it is to have infinite resistance, which means an open circuit and no power flows anywhere, or 0 resistance, which means a perfect wire with no voltage drop. Anything in between wastes energy, which means there's a voltage drop causing heat in the electronics.

So, if we want to control the power without wasting energy, we switch really fast between those two efficient states. One applies power and the other doesn't.

That's done with an H-bridge. It's just a PCB with MOSFETs that switch the power on and off really fast. It can control the polarity of both wires of the motor, so it needs 4 switches wired in an H. That's where the name comes from. The one we use is a Cytron MD25HV. Thanks to Cytron for sponsoring it! There aren't many H-bridges that handle these higher voltages, and this one worked perfectly for us.

Then we just need to figure out how much power to apply, by comparing the angle we have and the angle we want. That goes to a PID algorithm running on an ESP32, which outputs the PWM signal we talked about. That signal goes to the H-bridge, which powers the motor.

Now we need to tune the PID values so it delivers the right amount of power without oscillating.

You can see in the video how it responds to our commands. Oh, and the dashboard we built to control everything from our phones. We'll go into more depth on that in another post.

<video controls playsinline preload="metadata" style="width: 100%; max-width: 340px; display: block; margin: 1em auto; border-radius: 8px;">
  <source src="videos/actuator-gears-polished.mp4" type="video/mp4">
</video>

Steering system docs: [Assembly → Steering](../assembly/steering/index.md).

---

## A dashboard on your phone { #dashboard }

*2026-07-06*

When the kart misbehaves, you can't tell why unless you can see what it's thinking.

That's why we built a dashboard. It shows the kart's internal state live: the steering angle, the cones it detects, where it thinks it is, and where it wants to go. Without that you're debugging blind. You know it went the wrong way, but not which signal lied.

<video controls playsinline preload="metadata" style="width: 100%; max-width: 340px; display: block; margin: 1em auto; border-radius: 8px;">
  <source src="videos/phone-dashboard.mp4" type="video/mp4">
</video>

We were thinking about adding a panel with buttons and LEDs. Then we thought, why not a touchscreen like in the Formula car, so we can control the mission, the shutdown system state, and see values from the sensors? A dashboard where we can see and control everything.

After some thought we realized we already had the best possible dashboard: our phones. Great touchscreen, built-in battery, and you already have it always with you. A ROS 2 node on the Orin serves the web dashboard, and any phone can open it. Since AI makes this effortless, we tried it. And we loved it.

The only mess is the Wi-Fi. The Orin runs JetPack, NVIDIA's modified Ubuntu, and it can't hold two Wi-Fi connections at once, so we can't have internet and the local dashboard network at the same time. We opted to deploy online using Cloudflare and a custom domain, so we have internet and the dashboard is no longer local. This is practical for testing but requires a phone with a mobile hotspot. We'll soon try USB-tethering the phone's internet to the Orin, freeing the Wi-Fi for the local dashboard. That way, even without internet the dashboard still works.

Dashboard docs: [Software](../software/index.md).

---

## The first autonomous drive { #autonomous }

*2026-07-10*

This is the first time the kart really drives itself. It's jerky and slow, but it works.

<video controls playsinline preload="metadata" style="width: 100%; max-width: 720px; display: block; margin: 1em auto; border-radius: 8px;">
  <source src="videos/kart-first-autonomous-drive.mp4" type="video/mp4">
</video>

To get here, we first tuned the steering PID controller until it ran stably — values of 1.50, 0.0, 0.02, at 500 Hz on the ESP32.

For the control logic we used the most stupidly simple steering algorithm you can imagine: take the first two cones, average their positions, and point the wheels at that midpoint.

In parallel we're developing and testing Pure Pursuit, a Stanley controller, Model Predictive Control (MPC), and even an end-to-end neural network in a simulator. We'll compare all of them on the track soon — they didn't work in reality yet because they need more real-world tuning.

To find the cones from the cameras we use YOLOv11s. We took the foundation from [some old code](https://youtu.be/wZSFr2eYE4M) and significantly improved the training for our specific case.

The next step is enabling the ZED camera's built-in object tracking, specifically its Kalman filter. Right now the cones sometimes disappear or jump back and forth frame by frame. The Kalman filter will track them consistently, keeping their IDs and predicting positions even through dropped frames.

Software docs: [Software](../software/index.md).

---

## The PCB, explained { #pcb }

*2026-07-29*

<video controls playsinline preload="metadata" style="width: 100%; max-width: 720px; display: block; margin: 1em auto; border-radius: 8px;">
  <source src="videos/kart-medulla-pcb.mp4" type="video/mp4">
</video>

Gabriel Fernández Romero explains how our PCB works and why we need it. Thanks to **AISLER** for sponsoring the fabrication.

The main reason the board exists: the ESP32 only reads up to 3.3 V. The Festo pressure sensors output 0–10 V, one volt per bar, so they go through a voltage divider first.

The motor's hall sensors work at 5 V, but a divider there would degrade the signal. Those go through a Schmitt-trigger buffer instead, which also cleans it up.

Accelerating and braking need the opposite conversion. In manual mode the throttle signal comes from the pedal; in autonomous mode we have to generate it. One op-amp gives the 0–5 V throttle signal, and a second one on the same chip drives the proportional brake valve, which wants 0–10 V.

There are also two MOSFETs — one cuts the shutdown line with the safety switches, the other controls the compressor. And the wiring uses push-in connectors, so we can try things out without crimping wires.

Board docs: [Kart Medulla](../assembly/electronics/kart-medulla/index.md).

---

## The sensor that couldn't see a magnet { #as5600-magnet }

*2026-07-30*

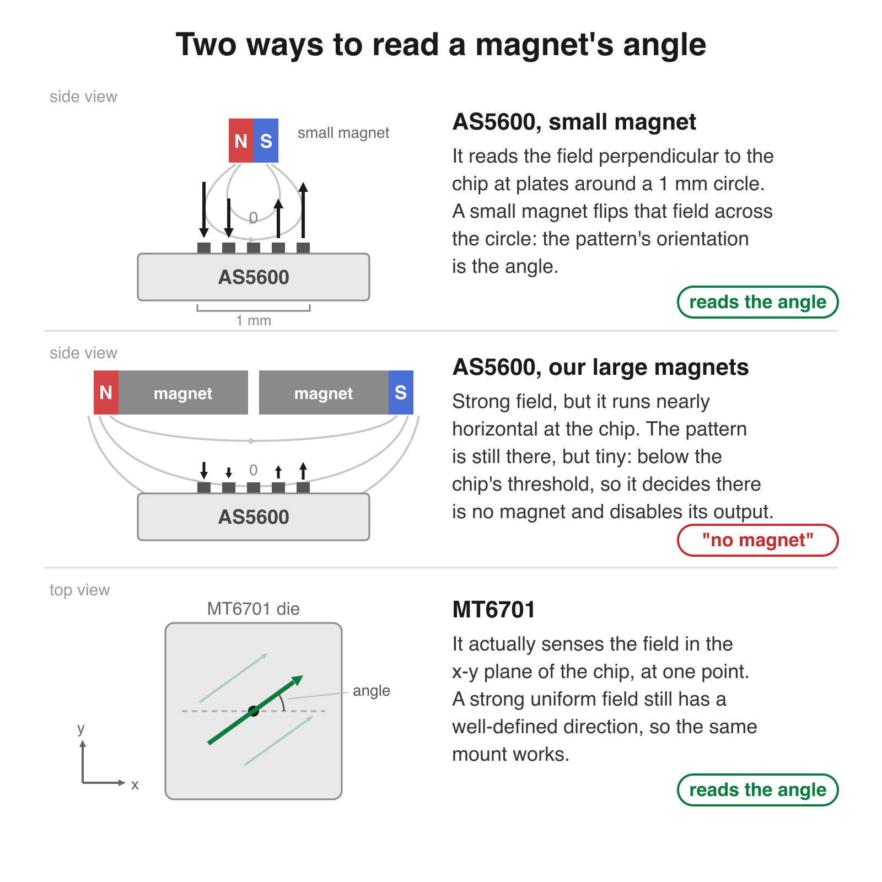
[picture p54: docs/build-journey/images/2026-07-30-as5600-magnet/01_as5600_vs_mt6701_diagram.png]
How the AS5600 and the MT6701 read a magnet's angle


Our steering angle sensor reported "no magnet" with the magnet touching the chip. The sensor was not broken, and the magnets are strong.

It started when we wanted to move the ESP32 and its PCB to the rear of the kart, next to the main computer, free from the dirt and bumps. The sensor gives us the angle over I²C, but at that distance the wire is too long for I²C. The AS5600 can supposedly output the angle as a PWM signal instead, but that never worked. While troubleshooting we found that even with the magnet touching the chip — still giving the correct angle over I²C — it reported "no magnet".

The catch is that the AS5600 is designed to work with a *small* diametrically magnetized magnet, not just any one. It measures the field only in the direction perpendicular to the chip, and compares the intensity around a small circle. If the magnet is large, the field across that circle is almost uniform — the pattern is still there, but it falls below the chip's threshold, so the AS5600 decides there is no magnet and disables its output. At the centre of the chip the field is always zero, but at the edges it should vary strongly: maximum along the North–South direction, zero at 90° to it. From the intensities around that circle it works out the angle.

We would rather have a chip that can take advantage of a strong magnet, so the alignment does not have to be perfect, and one that really does output the angle as PWM. So we have switched to the **MT6701**.

Steering sensor docs: [Angle Sensor](../assembly/steering/sensor/index.md).

---

*That's the latest post. New ones land roughly weekly — [follow on LinkedIn](https://www.linkedin.com/in/rubenayla/) to catch them as they ship, or check back here.*

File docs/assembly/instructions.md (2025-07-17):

# Assembly Instructions

This section contains instructions for assembling the kart.

# Stuff

- The red plastic piece of the steering column goes on top of the bolt that holds it
- The bearings on the wheels are separated with tube of ? ID x ? OD x ? length to allow compressing them with the bolts without applying constant shear force on the bearings
- ...

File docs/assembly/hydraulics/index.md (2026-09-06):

# Hydraulics

The kart keeps its original hydraulic brakes. They are what actually stops the wheels — the
[pneumatic system](../pneumatic-braking/index.md) is the actuator that squeezes them, both for
normal autonomous braking (ASB) and for the emergency circuit (EBS). This page covers the fluid
side: hoses, bleeding, and the pressure sensor that tells the kart how hard it is braking.

The installed brake components and compatible service-spare candidates are listed in the
[hydraulic brake BOM](bom.yaml).

## Brake lines

Flexible brake hoses with `M10x1.0 female inverted flare` connectors.

### Bleeding / purging

The lines have to be purged of air after any work that opens the circuit; trapped air makes the
pedal spongy and the pressure reading meaningless. Reference video for the procedure:
[youtu.be/dXhEvykyabk](https://youtu.be/dXhEvykyabk?si=LNnOBOaIlJ93uHi6).

## Brake pressure sensor — bought, not fitted

!!! warning "This sensor is on hand and unused"
    `~/dv/kart/pneumatics/README.md` records the Sensata unit as *"not used in this system"*, and the
    2026-04 Festo price sheet lists it as *"Not Festo; on hand, currently unused"*. Nothing on the
    kart currently measures hydraulic brake-line pressure. Treat everything below as the plan for
    when it goes in, not as installed hardware.

A **Sensata PTE7100**, recorded in the dv notes as **PTE/700-33**
([datasheet](../../assets/datasheets/sensata_pte7100_hermetic_analog_pressure_sensor_da-1919220.pdf)).
Photos of the actual unit are in `~/dv/kart/pneumatics/pictures/` (`6010450369185516303`,
`6010450369185516304`).

| | |
|---|---|
| Range | 0–200 bar |
| Output | 1–5 V, supply 8–32 Vdc |
| Pressure port | 7/16-20 UNF-2A (male) |
| Seal | HNBR o-ring |
| Electrical connector | Packard Metri-Pack 150 |
| Supplied with | Neither a mating connector nor a snubber — order both separately |

**Adapter to the brake line:** a `male M10x1.0 inverted flare to female 7/16-20 UNF` adapter, since
the sensor's port thread does not match the hoses.

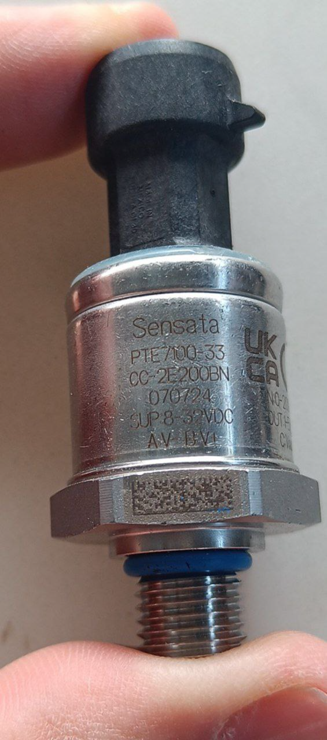
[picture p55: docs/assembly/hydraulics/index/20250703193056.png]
The Sensata pressure sensor with its adapter


When it is fitted, its signal goes to one of the Kart Medulla's two hydraulic-pressure ADC inputs —
see [Kart Medulla](../electronics/kart-medulla/index.md). Its 1–5 V swing is divided down on the
board before reaching the ESP32's 3.3 V ADC.

Not to be confused with the kart's **pneumatic** pressure sensors, which are fitted and reading:
those are Festo SDE5-D10 units on the EBS air circuit, covered on the
[Pneumatic Braking](../pneumatic-braking/index.md) page.

### Possible alternative

[Bosch Motorsport PSS-260](https://xtramotorsport.com/product/bosch-motorsport-pss-260-brake-pressure-sensor/)
(PN 0261545188) — 0.5–4.5 V, 0–260 bar. Not bought; kept as a fallback if the Sensata becomes hard
to source.

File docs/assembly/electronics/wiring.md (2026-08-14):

# Electrical Wiring

Complete electrical wiring diagram for the kart, covering the shutdown circuit, power distribution at multiple voltages, and signal routing between all subsystems.

## Wire Color Code

This is the colour convention **for the wiring we build ourselves** — the hand-made harness between subsystems. It is a house guideline, not a rule the whole kart obeys: this is a prototype assembled from third-party parts, and those parts keep their vendors' own colour codes. Two notable exceptions:

- **Off-the-shelf DC-DC power regulators** land on the rear **Wago** connectors with their own fixed output-wire colours, following the module's standard rather than this table.
- **Festo** sensor and valve cables follow **EN 60947-5-2** (see the [pressure-sensor note](#festo-pressure-sensor-connector-m8-3-pin) below) — e.g. blue is ground and black is a signal output, the opposite of this table.

Where we do run our own wire:

| Color | Meaning | Hex |
|---|---|---|
| **Black** | Power GND — return for motors, valves, coils, and the power rails | `#333` |
| **Black + white stripe** | Signal GND — return for sensors and analog/logic references | `#333` / `#fff` |
| **Red** | 12 V power | `#d32f2f` |
| **Orange** | 5 V power | `#e65100` |
| **Yellow** | 3.3 V power | `#f9a825` |
| **White / Gray** | Deliberately unassigned — carries no meaning | `#bbb` |

**White and gray are the escape hatch, and that is their job.** Every other colour in the
table is a promise about what the wire carries, so using one wrongly is worse than using
none: someone later reads the promise and trusts it. White carries no promise, so you can
wire anything with it — a one-off, a bodge, a bus nobody has a convention for — without
breaking the code or having to invent a new colour first. Reach for white whenever the
right colour is not obvious. Signal wires we run ourselves (I²C, analog, PWM) use white or
gray by default, unless a specific convention applies to that bus.

A **stripe** modifies the base colour rather than adding a second meaning, so the white
stripe on signal ground is not an exception to this: the wire is black, and black means
ground. Solid white and striped black are hard to confuse in the harness.

### Why two grounds

Motor, valve, and coil currents are large and switch fast. Sharing a return wire with a
sensor puts that current's voltage drop directly in series with the sensor reading, so the
measurement moves when the motor does. Separating the returns keeps that drop out of the
sensitive path.

Both grounds are the same electrical node — they are **joined at exactly one point**, the
star point. On this kart that point is the **rear ground Wago terminal block**, near the
battery and the 12 V / 24 V regulators; it appears in the wire list below as the device
`wago_gnd`. Two joins would create a loop and undo the separation, so no other place in the
harness may bond the two. The stripe is there so that anyone tracing the harness can tell,
without a meter, which return a wire belongs to and therefore where it is allowed to land.

If striped wire is hard to source in a given gauge, use plain black with a **white
heatshrink band at both ends** — same meaning, same rule.

## Global Wiring Diagram

Hand-crafted SVG. Real Festo product photos for the pneumatic brake chain (VPPM, EBS, ADN actuator); inline schematic-style symbols for the rest (battery cell stack, BLDC motor with U/V/W terminals, mushroom kill switches, op-amp triangle, SDC relay coil + NO contacts). [**Open full-size in a new tab ↗**](wiring/images/wiring-global.svg){ target="_blank" }

<object data="wiring/images/wiring-global.svg" type="image/svg+xml" style="width:100%;max-width:2000px;"></object>

> **Tip:** All switches in the shutdown chain are in series — opening any one cuts power to the relay coil, which disables the motor controller.

## Manual / autonomous mode switch

A single **DPDT** (double-pole double-throw) switch on the kart panel decides the mode. Both poles
are in use, and both are plain metal contacts — which is the point of the design:

- **Pole 1 — throttle source.** Selects what reaches the traction ESC's throttle input: the
  accelerator pedal in manual, or the medulla's autonomous command (`CMD_ACC_DAC`, out of the
  medulla on CN10.1) in autonomous.
- **Pole 2 — steering motor.** Breaks the cable from the Cytron H-bridge to the steering motor, so
  in manual mode the steering motor is physically disconnected from its driver.

**What this buys, and why it is a switch rather than electronics.** Manual mode does not depend on
the medulla, on firmware, or on anything being powered. With the whole electronics side dead, the
pedal still reaches the ESC and the steering motor is still disconnected, because metal is touching
metal. No software fault can accelerate or steer the kart while a human is driving it — the
firmware is not in the path to make a mistake in. Any scheme where a chip or a microcontroller
output performs this selection is strictly weaker, because it can only be as trustworthy as the
code and the supply behind it.

**The Cytron's 48 V supply is deliberately not switched.** It stays permanently powered on the
PACK48 rail. Gating it through the mode switch was tried and reverted: the inrush at every
switch-to-autonomous browned out the Orin. Only the motor cable is broken, not the driver's supply.

**The medulla cannot currently tell which mode the kart is in.** Nothing routes the switch position
back to it, so firmware knows only what it last commanded. The intended fix for the next board
revision is a **third pole** on the switch, shorting a sense wire to ground in autonomous against a
pull-up on the medulla — one wire, read-only, which firmware can observe but never drive. It is not
built yet; the medulla pin is part of the v2 pin allocation still being decided in `dv-hardware`.

## Wire list (whole kart)

One row per **net** (electrical node) across the whole kart — the tabular companion to the diagram above. The **Connected pins** column lists every `device.pin` tied together; medulla (the kart's ESP32-S3 interface PCB) `CNx.y` terminals map to GPIOs on the [Kart Medulla connector pinout](kart-medulla/index.md#connector-pinout-outside-world). This table is **generated** from [`wiring/wiring.yaml`](https://github.com/um-driverless/kart-docs/blob/main/docs/assembly/electronics/wiring/wiring.yaml) — edit the YAML, not the table; completeness is checked by `scripts/check_wiring.py`.

!!! note "Scope and source of truth"
    Only the **kart-medulla PCB** has a KiCad project (`dv-hardware`) as its authoritative netlist — trust that for the medulla-internal nets. The rest of the kart (power distribution, traction, shutdown chain, motor) is **not** in KiCad; those rows are transcribed from the diagram and subsystem docs and should be **field-verified** before you rely on them. Wire colours follow the [house code](#wire-color-code) for wiring we run ourselves; vendor cables (Festo, power modules) keep their own colours, and 48 V pack cabling has no assigned code colour.

<!-- WIRING_TABLE -->

## Festo pressure sensor connector (M8, 3-pin)

The two pneumatic-pressure sensors are **[Festo SDE5-D10-NF-Q6E-V-M8](https://www.festo.com/es/es/a/567465/)** (part 567465, 0–10 bar range, 0–10 V analog output; [datasheet](../../assets/datasheets/567465datasheet.pdf)). Each has an **M8×1, A-coded, 3-pin** plug and connects with the **[NEBU-M8G3-K-2.5-LE3](https://www.festo.com/es/es/a/541333/)** cable (part 541333, wire colours to EN 60947-5-2). Both sensors share this identical pinout.

| M8 pin | Cable wire | Function | On the kart |
|---|---|---|---|
| **1** | Brown (BN) | Supply + | 24 V rail — sensor rated 15–30 V DC. This 24 V is a *planned* shared supply with the VPPM valve (from a 9–36 V → 24 V buck-boost, **not yet fitted**); the SDE5 also runs fine at 15–19 V. |
| **3** | Blue (BU) | 0 V / GND | Common ground |
| **4** | Black (BK) | Analog output 0–10 V | Proportional to 0–10 bar; divided + clamped on the medulla (ESP32-S3 PCB) to ≤ 3.3 V before its ADC |

Socket face (looking into the cable's M8 socket): pin **4** top, **3** left, **1** right.

> **Watch the colours:** these are Festo's standard cable colours per EN 60947-5-2 — they do **not** follow the kart's colour code above. On this cable **black is the signal output (not ground)** and **blue is ground**. Wire by pin number, not by colour.

The outputs feed the ESP32 medulla as `PRESSURE_1` and `PRESSURE_2` (terminals CN7.1 / CN7.2) — see [Kart Medulla → Connector pinout](kart-medulla/index.md#connector-pinout-outside-world). The former `PRESSURE_3` terminal (CN5.2) has been **repurposed to the steering-angle PWM input** (see below), so it no longer reads a pressure sensor. Each sensor's supply and its divider/clamp live on the medulla PCB, not in the harness.

## Steering angle sensor wiring

The steering-angle sensor tells the medulla where the front wheels point, closing the steering position loop.

**A MagnTek MT6701** encoder, sending its angle as a **PWM duty cycle on a single wire** (3.3 V CMOS square wave, ~994 Hz frame), into the freed `PRESSURE_3` terminal. Mounted and reading on the kart since 2026-07.

One wire rather than a bus, because the run is long: the **kart-medulla PCB** is at the **rear** of the kart next to the Orin (they connect over USB), while the sensor stays on the steering shaft at the front — about **1.2 m** apart. I²C does not survive that: it is single-ended open-drain, easy to glitch alongside the 48 V motor phases, and one glitch on SCL hangs the bus — which the on-board PCF8574 shares, so a front-cable disturbance would take down more than the steering read. A PWM duty cycle on one wire is robust over the distance and never touches that bus. See [Angle Sensor](../steering/sensor/index.md).

| MT6701 module pin | Medulla terminal / ESP32-S3 | Notes |
|---|---|---|
| VCC | 3.3 V (CN1.1 / CN6.3) | 5 V only needed for a one-time EEPROM burn |
| GND | Signal GND (`GND_SIG`) | **Not yet resolved to a terminal.** CN1.3 / CN9.3 / CN10.3 are the medulla's ground terminals, but they are currently recorded on the *power* ground net, and this sensor's return belongs on [signal GND](#why-two-grounds). Landing it on a power-ground terminal would bond the two grounds a second time. Check the KiCad project for the kart-medulla PCB's analog ground before wiring — see the open task in `tasks.md`. |
| SDA | GPIO 8 (I²C) | MT6701 address 0x06 (PCF8574 is 0x20 — no clash). Used for config + a bench angle cross-check |
| SCL | GPIO 9 (I²C) | |
| OUT (PWM) | **CN5.2 → R8 → R9 → GPIO 1** | 20 kΩ series into the ESP32-S3 MCPWM capture. **Board rework: remove R10 only** (keep R8 + R9). |
| MODE | Tie for I²C/SSI | If left in ABZ mode, I²C won't respond |

The PWM wire is a plain signal line (kart color code: white/gray); keep it short and ideally twisted with its ground or shielded. Board topology after rework: `CN5.2 —[R8 10k]— node —[R9 10k]— GPIO 1 —[R10 removed]`. See [Angle Sensor](../steering/sensor/index.md) for why the MT6701 was chosen, and [Kart Medulla](kart-medulla/index.md#connector-pinout-outside-world) for the terminal-level detail.

## Festo valve & actuator connectors

Beyond the pressure sensors, the pneumatic brake chain uses two more Festo connector types. Full part detail is in the [Pneumatic Braking BOM](../pneumatic-braking/bom.md); the wiring-relevant summary:

- **[VPPM proportional brake valve](https://www.festo.com/es/es/a/571293/)** (VPPM-8L-L-1-G14-0L10H-V1P-S1C1, part 571293; [catalog doc](../../assets/datasheets/205274_documentation.pdf) · [datasheet](../../assets/datasheets/VPPM_en.pdf)) — sets the autonomous brake pressure. Cable **[NEBU-M12W8-K-2-N-LE8](https://www.festo.com/es/es/a/542256/)** (part 542256), **M12 8-pin shielded**. Supply 24 V (21.6–26.4 V), setpoint 0–10 V from the medulla brake DAC (MCP4922 channel B → ×2 op-amp), max draw ~300 mA. **Pins 1 and 5 are digital inputs D1/D2** (control-response select) — energising them locks out the valve's front-panel button config, so leave them per the datasheet. Take the per-wire colour map from the 542256 cable datasheet (linked in the BOM); it is deliberately not reproduced here rather than risk an unverified pinout.
- **Solenoid valve coils** (EBS = Emergency Braking System, plus the spare ASB = Autonomous Service Brake) — DIN form connectors, **not** M8/M12. The EBS coil ([VACF-B-C1-5](https://www.festo.com/es/es/a/8030810/), part 8030810) is **form C** and mates with the **[MSSD-EB](https://www.festo.com/es/es/a/151687/)** plug (part 151687); the spare ASB coil ([VACF-B-B2-5](https://www.festo.com/es/es/a/8030801/), part 8030801) is **form B** and needs its own plug — they are not interchangeable. Both coils are 12 V DC / 3.4 W off the 12 V rail. See the [BOM](../pneumatic-braking/bom.md) for the coil-interchangeability warning.

## Related Pages

- [Net Name Nomenclature](net-naming.md) — signal naming conventions across PCBs
- [Throttle Pedal](../powertrain/throttle-pedal.md) — pedal sensor wiring
- [Steering Angle Sensor](../steering/sensor/index.md) — AS5600 → MT6701 sensor choice and calibration
- [Kart Medulla (ESP32-S3)](kart-medulla/index.md#connector-pinout-outside-world) — microcontroller wiring connections
- [Pneumatic Braking](../pneumatic-braking/index.md) — ASB + EBS pneumatic circuit and valve coil wiring

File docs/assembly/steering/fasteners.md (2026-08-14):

# Steering Assembly Fasteners

## Fasteners Overview

This page documents all fasteners used in the steering assembly with precise identification using the annotated reference photo. Each bolt is numbered for easy identification during assembly or maintenance.

!!! warning "Critical Safety"
    Steering fasteners are safety-critical. Use specified torque values and threadlocker. Inspect regularly for looseness.

## Reference Photo

??? example "View steering assembly with numbered fasteners"
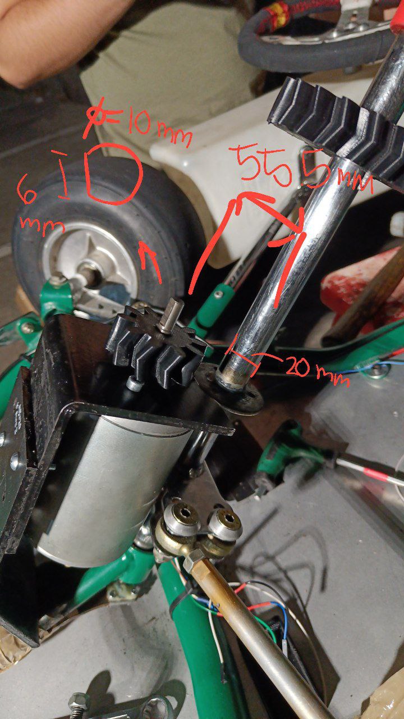
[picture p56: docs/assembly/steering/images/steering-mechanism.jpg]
Steering mechanism with bolt identification
    

    **Fastener Identification:**
    1. Coupling to motor bolts (4x M6x20)
    2. Main coupling bolt (1x M8x25)
    3. Sensor mounting screws (2x M3x8)

## Detailed Fastener Specifications

### Item #1: Coupling to Motor Bolts
- **Quantity**: 4 bolts
- **Size**: M6 x 20mm hex head cap screws
- **Location**: Motor flange to coupling connection
- **Torque**: 12 Nm
- **Material**: Steel, zinc plated
- **Installation**: Apply threadlocker, torque in cross pattern
- **Inspection**: Check weekly for looseness

### Item #2: Main Coupling Bolt
- **Quantity**: 1 bolt
- **Size**: M8 x 25mm hex head cap screw
- **Location**: Through steering shaft coupling
- **Torque**: 20 Nm
- **Material**: Steel, grade 8.8 (high strength)
- **Installation**: Critical connection - use threadlocker
- **Inspection**: Check bi-weekly, this bolt failure would disable steering

### Item #3: Sensor Mount Screws
- **Quantity**: 2 bolts
- **Size**: M3 x 8mm hex head cap screws
- **Location**: angle-sensor board to its 3D-printed adjustable mount
- **Torque**: 3 Nm (be careful not to over-torque small screws)
- **Material**: Steel, zinc plated
- **Installation**: Hand-tighten plus 1/4 turn
- **Inspection**: Monthly visual check

### Motor Bracket Bolts
- **Quantity**: 2 bolts
- **Size**: M6 x 30mm hex head cap screws
- **Location**: Steering motor to chassis mounting bracket
- **Torque**: 15 Nm
- **Material**: Steel, zinc plated
- **Installation**: Ensure motor alignment before final tightening
- **Inspection**: Weekly check for vibration loosening

## Assembly Instructions

### Installation Sequence
1. **Mount sensor first**: fit the MT6701 board to its printed mount with the Item #3 screws
2. **Position motor**: Mount motor to chassis with bracket bolts
3. **Install coupling**: Connect motor to shaft with Item #1 bolts
4. **Final connection**: Install main coupling bolt (Item #2)
5. **Test**: Verify smooth operation and sensor reading

### Critical Notes
- **Alignment**: Ensure motor shaft and steering shaft are properly aligned before tightening
- **Sensor position**: the sensor must be centred over the magnet at the right air gap. The printed mount is *adjustable* for exactly this — gap and angular zero are trimmed after assembly, not fixed by the print. See [Angle Sensor](sensor/index.md)
- **Threadlocker**: Use blue (medium strength) on all bolts except sensor screws

## Maintenance Schedule

| Fastener | Check Frequency | Torque Check | Notes |
|---|---|---|---|
| Item #1 (Coupling) | Weekly | Monthly | Critical for power transmission |
| Item #2 (Main bolt) | Bi-weekly | Bi-weekly | Most critical fastener |
| Item #3 (Sensor) | Monthly | Quarterly | Avoid over-torque |
| Bracket bolts | Weekly | Monthly | Check for vibration loosening |

## Troubleshooting

### Loose Steering Feel
- Check Item #2 main coupling bolt first
- Inspect Item #1 coupling bolts for looseness
- Verify motor bracket bolt tightness

### Sensor Reading Issues
- Check Item #3 sensor mount screws
- Verify sensor hasn't shifted position
- Ensure magnet alignment hasn't changed

## Procurement Information

### Estimated Costs
- **Total fastener cost**: ~€5.50 for complete steering assembly
- **Recommended spares**: 25% extra quantity

### Suppliers
- **McMaster-Carr**: Premium quality metric fasteners
- **Fastenal**: Industrial fastener supplier
- **Local automotive**: Grade 8.8 bolts available at auto parts stores

### Required Tools
- **Hex key set**: 3mm, 6mm, 8mm
- **Torque wrench**: 0-25 Nm range
- **Threadlocker**: Loctite 243 (blue, medium strength)

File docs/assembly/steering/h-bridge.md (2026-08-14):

# H-bridge data
- **Cytron MD25HV** (25 A cont, 60 A peak, 7V-58V)
    - Product page: <https://www.cytron.io/p-25amp-7v-58v-high-voltage-dc-motor-driver>
    - Datasheet: <https://docs.google.com/document/d/1xJHVG2dc3aEtedCHf3L9NzUy5KqpxeWjeS9Lfh9XuqA>
    - GitHub library: <https://github.com/CytronTechnologies/CytronMotorDriver>
    - Tutorial: <https://www.cytron.io/tutorial/controlling-md10c-with-arduino>
    - Tutorial: <https://www.instructables.com/Controlling-Motor-Speed/>
    - **Note**: Upgraded from MD30C to support 13S battery (41.6V-54.6V). MD30C was limited to 30V max.

### Reasoning
Suggested H-bridges by gpt:

- **Cytron MD25HV** (25 A cont, 60 A peak, 7V-58V) - **CURRENT CHOICE**
- ~~**Cytron MD30C** (30 A cont, 80 A peak, 5V-30V) - Insufficient voltage rating for 13S battery~~
- **Pololu VNH5019 Driver** (12 A cont, 30 A peak)
    - <https://www.pololu.com/product/1451?utm_source=chatgpt.com>
- ~~Sabertooth 2x32: Overkill but excellent for dual motors, up to 32 A per channel~~
- ~~Simple BTS7960: Cheap dual half-bridge module, supports 43 A per channel, needs external PWM and logic control~~
- ~~IBT-4~~
    - Needs two synced pwm signals to control the H bridge, so it's harder to use. Otherwise it would work and it's cheaper

## Alternative motor controllers (investigated, not adopted)

Beyond a plain H-bridge, a few integrated speed/servo controllers were considered. None replaced the MD25HV, but they're worth knowing about if the control approach is ever revisited.

??? info "Driver alternatives (click to expand)"

    #### VESC (Vedder Electronic Speed Controller)
    - **Advantages**: multi-purpose, can be reused for other systems.
    - **Implementation**: test with an existing unit first; ESP32 communication via UART at 3.3 V; keep the column's magnetic angle sensor as it is. Note: VESC DC mode doesn't include position control, so an external PID is still needed.
    - **Alternative unit**: [Flysky FSESC67100 V2 Pro on Wallapop](https://es.wallapop.com/item/flysky-fsesc67100-v2-pro-1133224964)

    #### Kelly Controller KDS series
    - **Link**: [Kelly Controller shop](https://kellycontroller.com/shop/kds/)
    - **Specs**: ~60 €, 48 V (max 60 V), 50 A.
    - **Control**: 0–5 V analog for power, REV/DIR signal for direction. Requires an external microcontroller with PID for position control.

    #### AllMotion EZSV23WV servo controller
    - **Link**: [AllMotion EZSV23WV](https://www.allmotion.com/ezsv23wv-servo-control)
    - Integrated servo-control solution.

    #### Generic PWM motor controller
    - **Link**: [Component Authority DC motor controller](https://componentauthority.com/products/dc-10-55v-max-60a-pwm-motor-speed-controller-cw-ccw-reversible-12v-24v-36v)
    - **Specs**: 10–55 V DC, max 60 A, CW/CCW reversible. Works like the current Cytron solution — use with an ESP32 for the same control method.

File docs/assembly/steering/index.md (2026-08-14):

# Steering System

For the kart to drive itself, something has to turn the wheels. The steering system is the drive-by-wire actuator that does it: a motor turns the steering column to whatever angle the autonomy stack asks for, in a closed loop against an angle sensor.

## Key dimensions

| Dimension | Value |
|---|---|
| Steering column diameter | 20 mm |
| Motor shaft / sun-gear bore | 10 mm |
| Planetary centre distance | 28 mm |
| Output gear-pair centre distance | 66 mm |

The **Fusion 360 model is the single source of truth** for all geometry. This table is a convenience copy for quick reference — if it ever disagrees with the CAD, the CAD wins. An early hand-measured photo of the mechanism is on the [previous designs](previous-designs.md) page.

## Actuator architecture — how we drive the column

The current design is a **rotary actuator on the steering column**: a salvaged DC motor geared down through a ~11:1 reducer turns the column directly, with an MT6701 magnetic encoder closing the loop. This is the second architecture the team built — the first was a Maxon linear actuator on the steering linkage, since dropped (see [previous designs](previous-designs.md)).

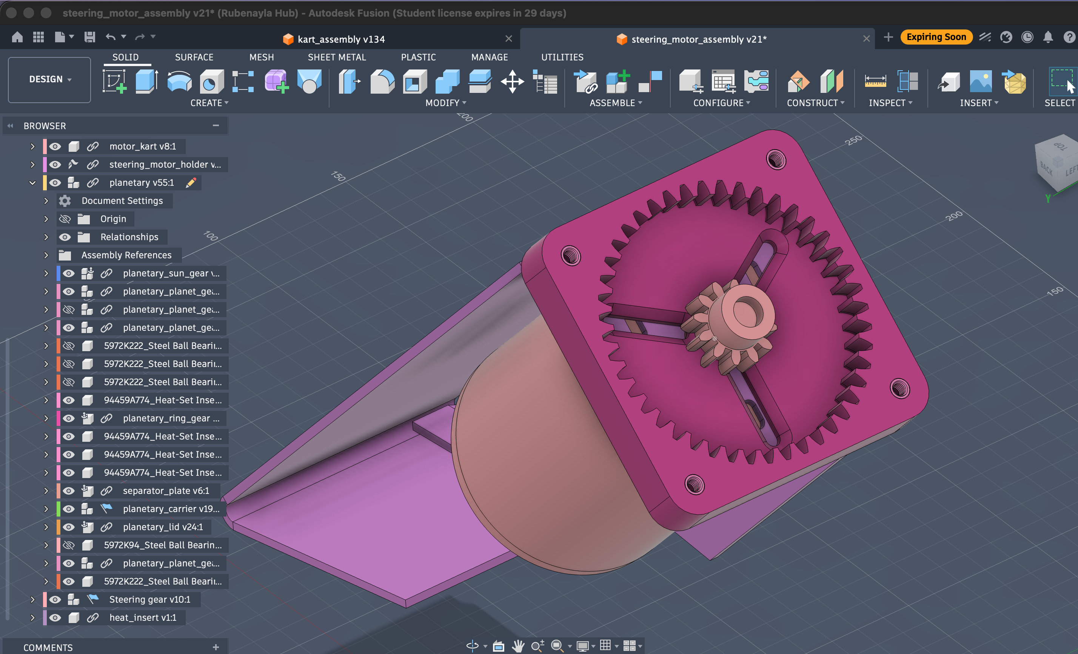
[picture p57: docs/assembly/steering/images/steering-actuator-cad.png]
Steering actuator in Fusion 360 — motor, planetary reducer and mount


*The current steering actuator (Fusion `steering_motor_assembly v21`): the DC motor (left) drives the planetary reducer mounted on the bracket; the carrier output goes on to the column gear.*

Why the current approach won:

- **Column-coaxial rotary, not linear.** Turning the column directly is mechanically simpler than pushing the linkage with a ball-screw, and it keeps the actuator compact and in line with the shaft.
- **Salvaged motor + printed reducer, not an off-the-shelf servo.** The motor was free (out of a discarded massage chair) and the reducer is a few euros of filament plus bearings. The whole actuator can be rebuilt or reprinted when it breaks — which, being printed gears, it does. Off-the-shelf gearmotors we considered (and didn't adopt) are on the [motor options](motor-options.md) page.
- **Plain PWM control, not a vendor ecosystem.** An H-bridge taking 3.3 V PWM from a microcontroller is something we can debug ourselves — the opposite of the EPOS/CANopen black box the Maxon path forced on us.
- **Backdrivable.** If the electronics die the wheels still turn by hand, because the planetary reducer backdrives.

The cost is durability: printed gears wear and the motor-shaft interface creeps. That trade — cheap and repairable over robust and expensive — is the through-line of the whole steering design.

## Signal chain

```
Orin (target angle)  ──USB──▶  ESP32-S3 / Kart Medulla
                                   │  PID
                                   ▼
             MT6701 ──angle──▶  PWM 3.3 V
             (column)               │
                                    ▼
                              MD25HV H-bridge ──▶ DC motor ──▶ ~11:1 reducer ──▶ column
```

## Main process

We need to move the steering shaft to the target angle.

1. The microcontroller reads the target position from the main computer (Orin) and the current position from the **MT6701 magnetic encoder** on the column, which sends the angle as a PWM duty cycle on one wire (see [Angle Sensor](sensor/index.md)).
    - The microcontroller is the ESP32-S3 on the [Kart Medulla](../electronics/kart-medulla/index.md) board (earlier prototypes used a Blue Pill / Teensy 4.0).
2. It computes a PWM duty cycle with a PID loop and sends 3.3 V PWM to the H-bridge.
3. The H-bridge (MD25HV) receives the PWM and powers the DC motor.
    - The MD25HV accepts control voltages from 1.8 V–30 V, so 3.3 V PWM from the ESP32 works directly.
    - [Datasheet](https://docs.google.com/document/d/1xJHVG2dc3aEtedCHf3L9NzUy5KqpxeWjeS9Lfh9XuqA)

See [H-bridge](h-bridge.md) and [Angle sensor](sensor/index.md) for the electronics, and [Reducer](reducer.md) for the gear train.

## Motor data

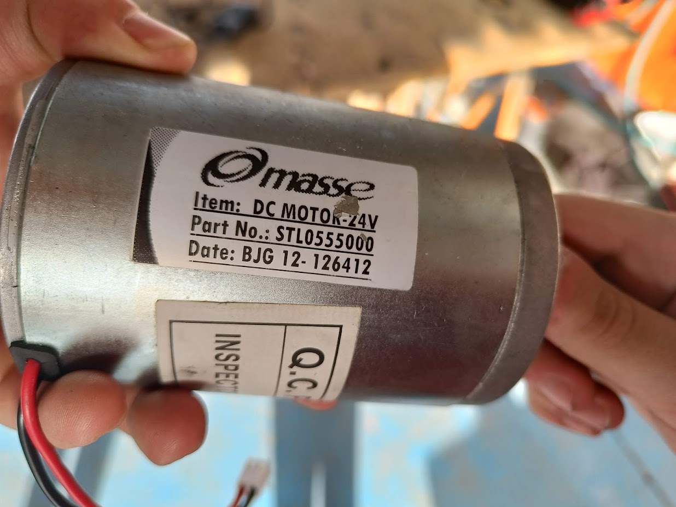
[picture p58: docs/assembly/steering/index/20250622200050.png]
Motor specifications


24 V geared DC motor (salvaged), driven from the battery through the Cytron MD25HV H-bridge with PWM. At stall it pulls 47 V × 43 A ≈ 2 kW; normal steering work is only ~47 W (see sizing below).

### Why a 24 V motor runs off the 48 V pack

This is deliberate, not an oversight — the motor is run at roughly twice its rated voltage and the
team accepts it. Rubén's reasoning, recorded 2026-08-08:

- **The duty is nothing like continuous.** Steering draws real power only while the column is
  actually turning, which is a fraction of a second at a time. Average load is far below the
  ~47 W the sizing calls for, and nowhere near the 2 kW stall figure.
- **The motor is well cooled** in its mounted position.
- **PWM is limited to 50 % duty**, so the average voltage the motor sees is about 24 V — its
  rating. Removing that limit is still considered safe given the duty cycle and cooling; the limit
  is margin, not the thing keeping the motor alive.

**Consequence for firmware:** the 50 % PWM cap exists for this hardware reason, so it should not be
raised as if it were an arbitrary tuning value without knowing that. Rated voltage is the reason it
is there.

The thing that would actually change this judgement is the duty cycle, not the voltage — if the
steering ever ends up holding a large angle against load for sustained periods (rather than moving
and releasing), the heat picture is different and this should be revisited.

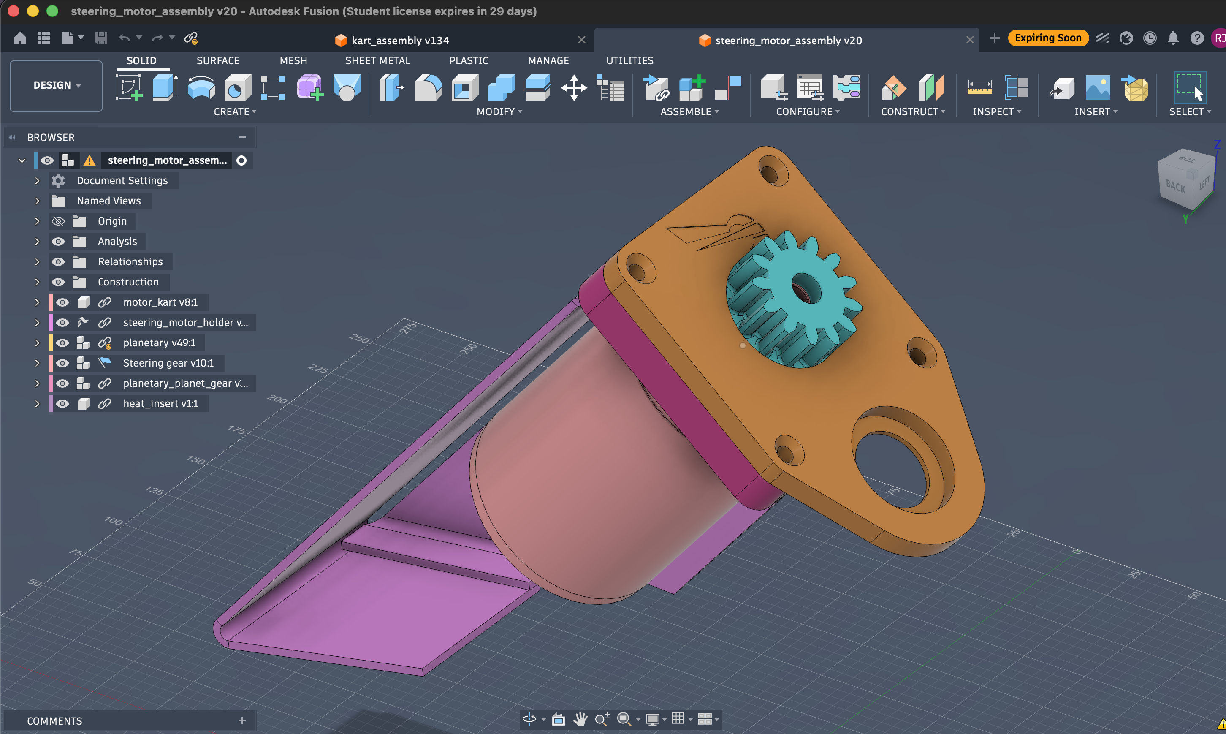
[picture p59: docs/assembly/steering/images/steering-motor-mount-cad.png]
Motor mounted to the bracket in Fusion 360, sun gear on the shaft


*Motor on its bracket (Fusion `steering_motor_assembly v20`): the carrier/sun mounts straight onto the motor shaft, so the reducer is coaxial with the motor.*

## Sizing the actuator

What the steering needs, all measured at the steering column (after the ~11:1 reduction). Figures from experience with the built actuator.

**Torque.** Turning the stopped wheels takes ~4 Nm to break the tyres loose; we size for **~8 Nm** with margin — the figure specified to Maxon in the 2025-01-07 YEP application.

**Speed.** The wheels swing ~±25° (≈50° lock-to-lock). The current motor sweeps that side to side in ~0.15 s on the ground, faster with the wheels lifted — about 6 rad/s (~56 rpm).

**Power** = torque × speed = 8 Nm × 6 rad/s ≈ **47 W**.

Power is never the constraint here. The 13S pack (~48 V) through the Cytron driver supplies far more than 47 W; at stall the motor pulls 47 V × 43 A ≈ 2 kW, nearly all of it heat. What the ~11:1 reduction buys is torque — it trades the motor's cheap speed for the ~8 Nm the column needs, so the motor isn't sitting near stall (and overheating) just to hold an angle.

### Design constraints

- **Available voltages**:
    - Battery: 13S (41.6 V – 54.6 V)
    - Regulated: 12 V, 5 V, 3.3 V
- **Budget**: < 1000 € for new components
- **Note**: integrated servos were considered as an alternative to separate electronics — see [motor options](motor-options.md).

## Reducer & alternative designs

The motor's speed is geared down to torque through a **~11:1 two-stage reducer** (a 3D-printed planetary + an output gear pair). The design, the gear-material saga, and the failure modes are on the **[Reducer](reducer.md)** page.

The other reducer types we weighed — cycloidal, folded compound gear train, worm, harmonic, belt — and the two we're keeping as live alternatives to print and test, are on **[Alternative reducer designs](alternatives/index.md)**.

## CAD

!!! info "CAD available on request"
    The steering assembly is modelled in Fusion 360. We haven't published the files here yet — if you'd like the CAD for your own build, [get in touch](../../contact.md). Reducer details are on the [Reducer](reducer.md) page.

## History

Earlier directions that were built and dropped — the Maxon EPOS linear actuator, the first 3-planet reducer, the gear-material progression — are on **[Previous designs](previous-designs.md)**.

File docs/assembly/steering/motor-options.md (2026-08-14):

# Steering Motor

The actuator sizing — torque, speed, and the power that follows — lives on the [steering page](index.md). Short version: the column needs ~8 Nm to turn the stopped wheels and ~56 rpm to sweep lock-to-lock in ~0.15 s, so about 47 W of mechanical work. With a ~48 V pack and the Cytron driver, electrical power is never the limit; the only real design lever is getting enough torque at the column, which the 11:1 reduction provides.

This page records the motor in use and the off-the-shelf alternatives the team looked at.

## Current setup (kept)

The steering actuator is a 24 V geared DC motor pulled out of a discarded massage chair, driven from the battery through the Cytron H-bridge, turning the steering column through a 3D-printed planetary at 11:1. Position feedback comes from an MT6701 magnetic encoder on the column. It turns the stopped wheels with ~8 Nm and sweeps lock-to-lock in ~0.15 s; at stall it has roughly 2 kW available, far more than the ~47 W the job actually needs. The motor was free, the planetary is a few euros of filament plus four 608 bearings and some M3 hardware, and nothing here had to be ordered.

The candidates below are worth knowing about but don't replace this setup.

## Why a Bosch wiper motor is interesting

A wiper motor is a permanent-magnet DC motor with a **worm gearbox built into the same casting**: motor + reduction + IP rating + automotive duty cycle in one part. Worm gearing is non-backdrivable, so the steering holds position with the power off — useful for failsafe.

Caveats:

- Non-backdrivable — fine for autonomous, but a manual-override fallback can't assume the motor freewheels when off.
- The output stub is built for the wiper arm, not a 10 mm coupling — needs an adapter.
- Two-speed wiper motors have three brushes; the third gives a higher-rpm tap.

## Interesting alternatives (not currently planned)

Off-the-shelf parts worth remembering if the salvage motor fails or a procurement window opens. The bar to clear is ~8 Nm at the column (more for cold-tyre / full-lock hard cases) at ~56 rpm. Most of these still need a reduction stage to get there.

| Part | V | Output speed | Torque | Power | Feedback | Indicative price | Comment |
|---|---:|---:|---:|---:|---|---:|---|
| **Bosch F006-B20-0xx** generic wiper | 12 | 33 / 51 rpm | ~23 Nm peak | ~80 W | none | ~€50–80 new, €5–15 salvage | Built-in worm clears the torque bar with margin; 51 rpm is just under the ~56 rpm target. Cheap reference point. |
| **Bosch WDD2** (0390249101) Wiper Direct Drive | 12 / 24 | up to ~63 cpm (≈ 80 rpm) | 12 Nm cont, 34 Nm stall | 50 W cont (8.3 A) | LIN/CAN bus, programmable angle/speed/torque | ~£972 / ~€1 140 ex VAT | Programmable angle/speed/torque over CAN, but costs more than the rest of the kart. Skip. |
| **Doga 319H** (e.g. 319.4846.30.00) wiper motor *with feedback* | 12 / 24 | 30 / 45 / **100 rpm** variants | 4–9 Nm nominal, **>60 Nm starting** | 70–170 W | Hall, up to 972 ppr | ~€150–250 (RS / OEM Automatic) | Most elegant — IP65 + 972 ppr Hall feedback in one part. The 100 rpm variant clears the speed target; nominal torque is marginal, so it may still want a light reduction. Worth it only if integrated feedback matters more than headroom. |
| **Doga 319.4860.30.00** | 24 | 30 rpm | 50 Nm | ~150 W | none | ~€200 (RS) | Plenty of torque, but 30 rpm is too slow for the ~56 rpm target. Skip. |
| Generic 24 V planetary gearmotor (GEMS / ISL / AliExpress) | 24 | 100 rpm typical | 20–30 Nm | 100–200 W | optional encoder | ~€80–150 | Backdrivable (different failsafe behaviour from a worm); still needs external reduction to match the current setup. |

If procurement ever opens up, the Doga 319H at 100 rpm is the most interesting — its 972 ppr Hall feedback would let us drop the separate MT6701 encoder and its wire from the Kart Medulla. Useful to know, not a planned change.

Sources for the candidate motors:

- [Bosch WDD2 Wiper Direct Drive — official product page](https://www.bosch-motorsport.com/products/actuators/wiper-direct-drive/wiper-direct-drive-wdd2/)
- [Bosch WDD2 retail listing — Swindon Powertrain](https://webshop.swindonpowertrain.com/index.php?route=product/product&product_id=62)
- [Doga 319H DC wiper motor with feedback — OEM Automatic](https://www.oem.co.uk/products/motors/dc-motors/dc-motor-with-right-angle-gearbox-_-C31193/doga-319h---dc-wiper-motor-with-feedback-_-P1965277)
- [Doga 319.4860.30.00 (50 Nm / 30 rpm) — RS Components](https://int.rsdelivers.com/product/doga/31948603000/doga-brushed-geared-dc-geared-motor-24-v-dc-50-nm/7736800)
- [Generic 24 V planetary gearmotors — GEMS Motor catalogue](https://gemsmotor.com/12v-24v-dc-gear-motor)

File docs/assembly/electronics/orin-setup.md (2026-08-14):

# Jetson AGX Orin — Setup from Scratch

Complete guide for setting up the Jetson AGX Orin with NVMe boot and all software for the autonomous kart.

## Hardware Overview

| Component | Value |
|---|---|
| Board | NVIDIA Jetson AGX Orin Developer Kit |
| Architecture | aarch64 (ARM64), 12 CPU cores, 62 GB RAM |
| GPU | Ampere (CUDA 12.6) |
| Storage | 57 GB eMMC (soldered) + 476 GB NVMe M.2 SSD |
| Display | **DisplayPort only** (no HDMI). Requires DP-to-HDMI adapter |
| Camera | ZED 2 stereo (USB) |
| ESP32 link | USB serial to the Kart Medulla ESP32 (no CAN — see note) |

!!! warning "No CAN bus on the kart"
    The kart **does not use a CAN bus**. The Orin talks to the Kart Medulla ESP32 over **USB serial** (a plain USB cable presenting a serial port), and the ZED camera is USB too. Sensors reach the ESP32 as analog signals or I²C, not CAN. The Orin module *does* expose two CAN controllers (`can0`/`can1`) on its carrier, but they are deliberately **left unused** on the kart — so ignore any `can0`/`can1` references, they are the Orin's onboard option, not a kart bus.

    CAN only enters the picture on the **Formula Student car**, where it becomes the vehicle bus (a CAN-reader PCB for the Orin exists for that integration). Adding CAN to the kart would only introduce transceivers, drivers, and an extra encode/decode hop for no benefit. If you find CAN setup steps (`can0`/`can1`, `ip link set canX`, SocketCAN) anywhere in the kart docs or configs, they do not apply to the kart. Source: `dv/history.md` 2026-07-14 "The kart uses no CAN"; `kart-brain/README.md` (ESP32 over UART/USB).

## Boot Chain

The Orin uses three storage devices to boot:

```
QSPI flash (on-chip)     →  First-stage bootloader (firmware)
eMMC (57 GB, soldered)    →  Second-stage bootloader + boot partition
NVMe M.2 SSD (476 GB)    →  Ubuntu root filesystem (where the OS lives)
```

**Boot sequence:** QSPI → eMMC bootloader → NVMe root filesystem

- **QSPI**: Tiny on-chip flash. Holds the first code the CPU runs at power-on.
- **eMMC**: Internal storage soldered to the board. After NVMe flash, it only holds a small bootloader — not a full OS.
- **NVMe**: The M.2 SSD plugged into the board. This is where Ubuntu and all software lives, with ~435 GB available.

The flash tool writes to all three. This is expected.

!!! tip "Verify NVMe boot"
    After setup, `df -h /` should show `/dev/nvme0n1p1`, NOT `/dev/mmcblk0p1`.

## Software Stack

| Software | Version | Installed via |
|---|---|---|
| JetPack | 6.2.2 (L4T R36.5) | Flash (see below) |
| Ubuntu | 22.04 | Flash |
| CUDA | 12.6 | `sudo apt install nvidia-jetpack` |
| cuDNN | 9.x | `sudo apt install nvidia-jetpack` |
| TensorRT | 10.x | `sudo apt install nvidia-jetpack` |
| ROS 2 | Humble | apt (ROS 2 repos) |
| ZED SDK | 4.2 | Installer from Stereolabs (L4T 36.4 build, compatible with 36.5) |
| PyTorch | 2.5.0 (Jetson build) | NVIDIA Jetson AI Lab wheels |
| Python | 3.10 (system) | Pre-installed |

!!! note "Why ZED SDK 4.2 and not 5.2?"
    ZED SDK 5.2 does not provide a build for L4T 36.5 as of February 2026. The 4.2 build for L4T 36.4 installs successfully on L4T 36.5 with a compatibility warning. Upgrade when a 5.2 build for L4T 36.5 becomes available.

!!! note "Why JetPack 6.2.2 and not JetPack 7?"
    JetPack 7 does not support AGX Orin as of February 2026. Only the newer Jetson Thor family is supported. Orin support is expected in JetPack 7.2 (Q2 2026). Our full stack (ROS 2 Humble, ZED SDK, PyTorch, Ultralytics/YOLOv11) is confirmed compatible with JetPack 6.2.2.

## Flashing to NVMe

### What you need

- **Flash host**: x86_64 Linux machine (Ubuntu 22.04 or 24.04). We use the y540 laptop.
- **USB-C cable**: Data-capable (not charge-only)
- **Monitor + keyboard**: For the first-boot setup wizard

### Step 1: Prepare the flash host

```bash
# Install dependencies
sudo apt-get install -y abootimg binfmt-support binutils cpio cpp \
  device-tree-compiler dosfstools lbzip2 libxml2-utils nfs-kernel-server \
  python3-yaml sshpass udev

# Download L4T R36.5 BSP and root filesystem (~2.4 GB total)
mkdir -p ~/jetson-flash && cd ~/jetson-flash
wget https://developer.nvidia.com/downloads/embedded/l4t/r36_release_v5.0/release/Jetson_Linux_r36.5.0_aarch64.tbz2
wget https://developer.nvidia.com/downloads/embedded/l4t/r36_release_v5.0/release/Tegra_Linux_Sample-Root-Filesystem_r36.5.0_aarch64.tbz2

# Extract
tar xf Jetson_Linux_r36.5.0_aarch64.tbz2
sudo tar xpf Tegra_Linux_Sample-Root-Filesystem_r36.5.0_aarch64.tbz2 -C Linux_for_Tegra/rootfs/
cd Linux_for_Tegra/
sudo ./tools/l4t_flash_prerequisites.sh
sudo ./apply_binaries.sh
```

### Step 2: Put the Orin in Recovery Mode

Connect the USB-C cable from the flash host to the Orin's **flashing port** (the USB-C port next to the 40-pin GPIO header, NOT the power port).

**If the Orin is powered off:**

1. Press and hold the **Force Recovery button** (middle button)
2. Power on (press the Power button)
3. Release both buttons after ~2 seconds

**If the Orin is powered on:**

1. Press and hold the **Force Recovery button** (middle button)
2. Press and release the **Reset button** (leftmost button)
3. Release the Force Recovery button after ~2 seconds

**Verify** on the flash host:

```bash
lsusb | grep -i nvidia
# Should show: 0955:7023 NVIDIA Corp. APX  (recovery mode)
# NOT: 0955:7020  (normal mode)
```

### Step 3: Flash

```bash
cd ~/jetson-flash/Linux_for_Tegra

sudo ./tools/kernel_flash/l4t_initrd_flash.sh \
  --external-device nvme0n1p1 \
  -c tools/kernel_flash/flash_l4t_t234_nvme.xml \
  --showlogs \
  -p "-c bootloader/generic/cfg/flash_t234_qspi.xml" \
  --network usb0 \
  jetson-agx-orin-devkit \
  nvme0n1p1
```

This takes ~10-20 minutes. The output ends with `Flash is successful`.

### Step 4: First boot

!!! warning "First boot takes time"
    After flash, the Orin takes ~5 minutes with no display signal while initializing. If no signal after 5 minutes, power cycle (hold power button 5 seconds, then press again). After power cycle, BIOS appears in seconds, then Ubuntu boots in ~2 minutes. There may be brief periods of no signal during boot — this is normal.

Complete the Ubuntu setup wizard:

- Username: `orin`
- Password: See `.env` file (not committed — ask the team)
- Computer name: `orin`

## Post-Flash Setup

!!! warning "Credentials required"
    Several steps below need passwords that are **not committed to this repo**. Copy `.env.example` to `.env` and fill in the values before starting. Ask the team if you don't have them.

### Connect to WiFi

Connect to the university network during the first-boot wizard or from Settings:

| Field | Value |
|---|---|
| Network | `Robots_urjc` |
| Password | See `.env` file (not committed — ask the team) |

### Software Installation

### 1. Set power mode

The Orin defaults to 30W. Switch to 50W for full performance (requires reboot):

```bash
sudo nvpmodel -m 3   # MODE_50W (type "yes" when prompted to reboot)
```

After reboot, verify: `sudo nvpmodel -q` → `MODE_50W`.

### 2. JetPack SDK (CUDA, cuDNN, TensorRT)

JetPack comes pre-installed with the flash. Add CUDA to your PATH:

```bash
echo 'export PATH=/usr/local/cuda/bin:$PATH' >> ~/.bashrc
echo 'export PATH=$HOME/.local/bin:$PATH' >> ~/.bashrc
source ~/.bashrc
```

Verify:

```bash
nvcc --version   # Should show CUDA 12.6
dpkg -l | grep tensorrt   # Should show TensorRT 10.x
```

### 3. Max clocks on boot

By default the Orin throttles CPU/GPU clocks to save power. `jetson_clocks` unlocks maximum frequency — essential for real-time YOLO inference (~75 Hz vs ~39 Hz without it).

```bash
# Run now
sudo jetson_clocks

# Persist across reboots
sudo tee /etc/systemd/system/jetson-clocks.service > /dev/null << 'EOF'
[Unit]
Description=Maximize Jetson clocks
After=multi-user.target

[Service]
Type=oneshot
ExecStart=/usr/bin/jetson_clocks

[Install]
WantedBy=multi-user.target
EOF
sudo systemctl enable jetson-clocks
```

### 4. ROS 2 Humble

```bash
sudo apt install -y software-properties-common curl
sudo curl -sSL https://raw.githubusercontent.com/ros/rosdistro/master/ros.key \
  -o /usr/share/keyrings/ros-archive-keyring.gpg
echo "deb [arch=$(dpkg --print-architecture) signed-by=/usr/share/keyrings/ros-archive-keyring.gpg] \
  http://packages.ros.org/ros2/ubuntu $(. /etc/os-release && echo $UBUNTU_CODENAME) main" \
  | sudo tee /etc/apt/sources.list.d/ros2.list > /dev/null
sudo apt-get update
sudo apt-get install -y ros-humble-desktop ros-humble-vision-msgs ros-dev-tools
echo "source /opt/ros/humble/setup.bash" >> ~/.bashrc
```

### 5. ZED SDK

```bash
cd /tmp
wget -q "https://download.stereolabs.com/zedsdk/4.2/l4t36.4/jetsons" -O ZED_SDK.run
chmod +x ZED_SDK.run
./ZED_SDK.run -- silent skip_tools skip_samples
```

Install the JPEG dependency needed by the ZED ROS wrapper:

```bash
sudo apt-get install -y libturbojpeg0-dev
```

After installing, add the `orin` user to the `zed` and `dialout` groups (SDK access + serial port):

```bash
sudo usermod -aG zed,dialout orin
```

Log out and back in (or reboot) for the group to take effect.

### 6. PyTorch

!!! warning "Use `--index-url`, not `--extra-index-url`"
    Using `--extra-index-url` may pull the CPU-only wheel from PyPI instead of the Jetson CUDA build. Use `--index-url` to prioritize the Jetson index.

```bash
pip3 install --no-cache-dir \
  --index-url https://pypi.jetson-ai-lab.dev/jp6/cu126 \
  --extra-index-url https://pypi.org/simple \
  torch torchvision
pip3 install --no-cache-dir 'numpy<2' ultralytics pyyaml
```

PyTorch on Jetson needs NVIDIA shared libraries in `LD_LIBRARY_PATH`:

```bash
echo 'export LD_LIBRARY_PATH=$HOME/.local/lib/python3.10/site-packages/nvidia/cusparselt/lib:$HOME/.local/lib/python3.10/site-packages/nvidia/nvjitlink/lib:$LD_LIBRARY_PATH' >> ~/.bashrc
source ~/.bashrc
```

Verify:

```bash
python3 -c "import torch; print(torch.__version__, torch.cuda.is_available())"
# Should show: 2.5.0a0+... True
```

!!! warning "numpy must be < 2"
    OpenCV on the Jetson was compiled against numpy 1.x. Installing numpy 2 will break `cv2`.

### 7. Export YOLO TensorRT engine

The YOLO model ships as a `.pt` (PyTorch) file. For real-time inference on the Orin, export it to a TensorRT `.engine` file (takes ~3-4 minutes, only needed once per model):

```bash
cd ~/kart-brain
python3 -c "from ultralytics import YOLO; m = YOLO('models/perception/yolo/ruben_yolov11n_2026_03.pt'); m.export(format='engine', imgsz=320, half=True)"
```

Rename the output to include the hardware and TensorRT version:

```bash
mv models/perception/yolo/ruben_yolov11n_2026_03_320.engine \
   models/perception/yolo/ruben_yolov11n_2026_03_320_orin_trt10.engine
```

!!! warning "Always export with `half=True`"
    FP16 inference is ~2x faster than FP32 on the Orin's Ampere GPU. Never export without `half=True`.

This `.engine` file is committed to the repo. Re-export when the model changes or after a CUDA/TensorRT upgrade.

### 8. Clone repositories

```bash
cd ~
git clone https://github.com/UM-Driverless/kart-brain.git
git clone https://github.com/UM-Driverless/kart-medulla.git
```

### 9. Build kart-brain

First install all ROS 2 dependencies automatically:

```bash
cd ~/kart-brain
source /opt/ros/humble/setup.bash
rosdep install --from-paths src --ignore-src -r -y
```

Then build (always use `--symlink-install` so Python/launch file edits take effect without rebuilding):

```bash
colcon build --symlink-install
echo "source ~/kart-brain/install/setup.bash" >> ~/.bashrc
```

See the [kart-brain repo](https://github.com/UM-Driverless/kart-brain) for package details and usage.

### 10. PlatformIO (ESP32 flashing)

Install PlatformIO to flash [kart-medulla](https://github.com/UM-Driverless/kart-medulla) firmware to the ESP32 directly from the Orin:

```bash
pip3 install platformio
```

Flash the firmware (ESP32 must be connected via USB):

```bash
cd ~/kart_medulla
# The kart's board is an ESP32-S3 and enumerates as /dev/ttyACM0 on the Orin.
# Stop kart-brain first — it holds the serial port.
sudo systemctl stop kart-brain
~/.local/bin/pio run --target upload --environment esp32-s3-devkitc-1 --upload-port /dev/ttyACM0
sudo systemctl start kart-brain
```

!!! note "ESP32 bootloader mode"
    If flashing hangs at "Connecting...", put the board in bootloader mode: hold **BOOT**, press **EN**, release **BOOT**. The ESP32-S3 has built-in USB-Serial-JTAG and typically does not need this.

### 11. AnyDesk (remote desktop)

```bash
curl -fsSL https://keys.anydesk.com/repos/DEB-GPG-KEY \
  | sudo gpg --dearmor -o /usr/share/keyrings/anydesk-archive-keyring.gpg
echo "deb [arch=arm64 signed-by=/usr/share/keyrings/anydesk-archive-keyring.gpg] \
  http://deb.anydesk.com/ all main" \
  | sudo tee /etc/apt/sources.list.d/anydesk-stable.list > /dev/null
sudo apt-get update
sudo apt-get install -y anydesk
```

After installing AnyDesk, configure Xorg for headless operation (no physical monitor):

```bash
sudo mkdir -p /etc/X11/xorg.conf.d
sudo tee /etc/X11/xorg.conf.d/10-virtual-display.conf > /dev/null << 'EOF'
Section "Device"
    Identifier "Tegra"
    Driver "nvidia"
    Option "AllowEmptyInitialConfiguration" "true"
    Option "ConnectedMonitor" "DFP-0"
EndSection

Section "Screen"
    Identifier "Default Screen"
    Device "Tegra"
    DefaultDepth 24
    SubSection "Display"
        Depth 24
        Virtual 1920 1080
    EndSubSection
EndSection
EOF
sudo systemctl enable anydesk
```

Set a password for unattended access (so you can connect without anyone at the screen):

```bash
echo "$ANYDESK_PASSWORD" | sudo anydesk --set-password
```

Get the AnyDesk ID (share this with the team):

```bash
anydesk --get-id
```

After reboot, the display may default to 1024x768. Set 1600x900 (max supported by the dummy plug):

```bash
DISPLAY=:0 xrandr --output DP-0 --mode 1600x900
```

!!! note "Why `ConnectedMonitor DFP-0`?"
    The DP-to-HDMI adapter with a dummy HDMI plug doesn't provide proper EDID. Without this option, the NVIDIA driver sees both DFP-0 and DFP-1 as "disconnected", so Xorg has no screen and AnyDesk gets a black framebuffer. Forcing `ConnectedMonitor DFP-0` makes the driver create a framebuffer on the DisplayPort output regardless. The dummy plug caps resolution at 1600x900.

### 12. Disable WiFi Power Saving

WiFi power management causes intermittent SSH dropouts — the kernel puts the adapter to sleep under load. Disable it permanently:

```bash
# Disable now
sudo iw dev wlP1p1s0 set power_save off

# Persist across reboots (runs on every WiFi connect)
echo '#!/bin/bash
iw dev wlP1p1s0 set power_save off' | sudo tee /etc/NetworkManager/dispatcher.d/99-wifi-powersave-off
sudo chmod +x /etc/NetworkManager/dispatcher.d/99-wifi-powersave-off
```

!!! note "Interface name"
    The WiFi interface is `wlP1p1s0` on the AGX Orin (not `wlan0`). Verify with `ip link show`.

### 13. Cloudflare Tunnel (remote SSH from anywhere)

This lets anyone on the team SSH into the Orin from outside the university network — no open ports, no VPN.

#### On the Orin

```bash
# Install cloudflared (ARM64)
wget -O /tmp/cloudflared.deb \
  https://github.com/cloudflare/cloudflared/releases/latest/download/cloudflared-linux-arm64.deb
sudo dpkg -i /tmp/cloudflared.deb

# Authenticate with Cloudflare (opens a browser — select the rubenayla.xyz zone)
cloudflared tunnel login

# Create the tunnel and DNS route
cloudflared tunnel create orin
cloudflared tunnel route dns orin orin.rubenayla.xyz
cloudflared tunnel route dns orin kart.rubenayla.xyz
```

Then create the config file. Replace `TUNNEL_ID` with the ID printed by `tunnel create`:

```bash
sudo mkdir -p /etc/cloudflared
sudo tee /etc/cloudflared/config.yml > /dev/null << EOF
tunnel: TUNNEL_ID
credentials-file: /etc/cloudflared/TUNNEL_ID.json

ingress:
  - hostname: orin.rubenayla.xyz
    service: ssh://localhost:22
  - hostname: kart.rubenayla.xyz
    service: http://localhost:9090
  - service: http_status:404
EOF

# Copy credentials to the system config directory
sudo cp ~/.cloudflared/TUNNEL_ID.json /etc/cloudflared/

# Install and start as a system service
sudo cloudflared service install
sudo systemctl enable --now cloudflared
```

#### On each team member's machine

1. Install `cloudflared`:
    - macOS: `brew install cloudflared`
    - Ubuntu/Debian: `wget https://github.com/cloudflare/cloudflared/releases/latest/download/cloudflared-linux-amd64.deb && sudo dpkg -i cloudflared-linux-amd64.deb`
    - Windows: `winget install Cloudflare.cloudflared`

2. Create the sockets directory and add to `~/.ssh/config`:
    ```bash
    mkdir -p ~/.ssh/sockets
    ```
    ```
    Host orin-remote
        HostName orin.rubenayla.xyz
        User orin
        IdentityFile ~/.ssh/id_ed25519
        ProxyCommand cloudflared access ssh --hostname %h
        ControlMaster auto
        ControlPath ~/.ssh/sockets/%r@%h-%p
        ControlPersist 10m
    ```

    `ControlMaster` reuses a single SSH connection for all sessions — subsequent commands connect in ~50ms instead of ~400ms.

3. Send their public key (`cat ~/.ssh/id_ed25519.pub`) to be added to the Orin's `~/.ssh/authorized_keys`.

No Cloudflare account needed for team members — only the tunnel owner.

!!! tip "Generate an SSH key if you don't have one"
    ```bash
    ssh-keygen -t ed25519
    ```

### 14. Wi-Fi access-point mode (`kart-ap`)

Since 2026-07-06 the Orin boots as **its own Wi-Fi access point** instead of joining lab Wi-Fi. Phones and laptops connect directly to the kart's own network and reach the dashboard at a fixed address — no router, no venue Wi-Fi, no IP hunting in the middle of a field.

| Field | Value |
|---|---|
| Connection name (NetworkManager) | `kart-ap` |
| SSID | `kart` |
| Host IP (dashboard) | `http://10.42.0.1` |
| Autoconnect priority | 200 (wins over `Robots_urjc`, which is 10) |

The Orin's single Wi-Fi radio can hold **one** Wi-Fi connection at a time — either it joins an existing network for internet, or it serves its own AP. Access-point mode is a **NetworkManager hotspot** (shared mode): NetworkManager runs DHCP + NAT and places the host at its default shared-subnet address `10.42.0.1`. A quick one-off hotspot on the Orin looks like:

```bash
# wlP1p1s0 is the Orin's Wi-Fi interface (see step 12; NOT wlan0)
nmcli dev wifi hotspot ifname wlP1p1s0 ssid kart password <pw>
```

The deployed setup makes this a persistent connection profile named `kart-ap` with `autoconnect-priority 200`, so it comes up automatically at boot. A second phone joins SSID `kart` and opens `http://10.42.0.1` for the dashboard.

!!! note "Internet while in AP mode (optional)"
    Because the radio is busy serving the AP, the Orin has no internet from Wi-Fi. To give it internet anyway, plug a phone into the Orin over USB with USB tethering on — it appears as a `usb0` interface and carries the connection over the cable, leaving the radio free for the AP. NetworkManager shared mode NATs, so a dashboard phone on the AP can even reach the internet through the Orin → cable → tethering-phone chain. Source: `dv/tasks/usb-tethering-dashboard.md`, `dv/README.md`, `dv/history.md` 2026-07-06/07-14.

## Verification Checklist

- [ ] Power mode: `sudo nvpmodel -q` → `MODE_50W`
- [ ] Max clocks: `sudo jetson_clocks` and service enabled
- [ ] NVMe is root: `df -h /` shows `/dev/nvme0n1p1`
- [ ] CUDA: `nvcc --version` → 12.6
- [ ] TensorRT: `dpkg -l | grep tensorrt` → 10.x
- [ ] PyTorch GPU: `python3 -c "import torch; print(torch.cuda.is_available())"` → True
- [ ] ROS 2: `ros2 --help`
- [ ] ZED camera: `ls /dev/video*` (after plugging in)
- [ ] kart-brain built: `ros2 pkg list | grep kart`
- [ ] SSH access: `ssh orin` from Mac
- [ ] AnyDesk: working with dummy HDMI plug, unattended password set
- [ ] Cloudflare Tunnel: `ssh orin-remote` works from outside the network
- [ ] Dashboard: [kart.rubenayla.xyz](https://kart.rubenayla.xyz) loads and accepts password
- [ ] WiFi power save off: `iw dev wlP1p1s0 get power_save` → `Power save: off`
- [ ] Access point: SSID `kart` is broadcast and `http://10.42.0.1` loads the dashboard from a phone

## Network Access

| Method | Address | Notes |
|---|---|---|
| Kart access point | Join Wi-Fi `kart`, open `http://10.42.0.1` | Default field method. Orin is its own AP (`kart-ap`) — no router needed |
| SSH (local WiFi) | `ssh orin` (10.7.20.x, DHCP) | Only if the Orin is joined to lab Wi-Fi instead of AP mode. IP may change |
| SSH (remote) | `ssh orin-remote` (via Cloudflare Tunnel) | Works from anywhere. Requires `cloudflared` installed locally |
| Dashboard (local) | `http://<orin-ip>:9090` | Must be on same network |
| Dashboard (remote) | [kart.rubenayla.xyz](https://kart.rubenayla.xyz) (via Cloudflare Tunnel) | Works from any network. Password required (default: `0`) |
| AnyDesk | Via ID (see `.env` for password) | Needs dummy HDMI plug for display |

!!! tip "Always verify IPs"
    The university network uses DHCP. Run `hostname -I` on the Orin to get the current IP. Update `~/.ssh/config` if it changed.

## Known Issues

| Issue | Workaround |
|---|---|
| ZED "CAMERA NOT DETECTED" | Kill all stale ROS processes (`sudo killall -9 component_container_isolated`), clean shared memory (`rm -rf /dev/shm/fastrtps_*`), then relaunch. Do NOT unplug the camera. |
| torch `libcusparseLt.so.0` not found | Add NVIDIA pip package libs to `LD_LIBRARY_PATH` (done in step 5) |
| PyTorch installs CPU-only wheel | Use `--index-url` (not `--extra-index-url`) for the Jetson AI Lab index (see step 5) |
| numpy >= 2 breaks cv2 | Pin to `numpy<2` |
| ZED SDK not readable by `orin` user | Add `orin` to `zed` group: `sudo usermod -aG zed orin` (done in step 4) |
| AnyDesk resolution too low | Run `DISPLAY=:0 xrandr --output DP-0 --mode 1600x900` after reboot |
| No HDMI port | Use DP-to-HDMI adapter + dummy HDMI plug for headless AnyDesk |

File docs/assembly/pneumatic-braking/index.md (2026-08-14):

# Pneumatic Braking

The kart needs two braking functions on one pneumatic actuator:

- **ASB (Autonomous Service Brake)** — proportional braking the main computer modulates while the kart is driving itself. Handled by the **VPPM** proportional valve.
- **EBS (Emergency Brake System)** — full braking that must engage automatically whenever the shutdown circuit opens or power is lost. Handled by the **EBS** solenoid valve.

The actuator is **air-to-apply**: pressure extends the cylinder onto the brake, and venting lets the return spring release it. The low-pressure reservoir stores enough air to keep braking after a shutdown.

## Validated design

This is the circuit we **built and physically validated (May 2026)**. It uses an **OR / shuttle valve** to merge the two branches, and it has **no isolation valve in series with the proportional valve** — testing confirmed none is needed (see the two sections below).

<object data="images/ebs-validated.svg" type="image/svg+xml" style="width:100%;max-width:920px;"></object>

> **Tip:** Click any component in the diagram to open its Festo product page. Yellow dots are CK compression fittings; blue lines are tubing; grey dashed lines are exhaust.

> **Source side under revision (2026-07).** The May 2026 validation used a VEVOR 6 L compressor+tank (max ~8.3 bar). The current plan drops that combo for a **salvaged portable inflator (motor + piston only, no original electronics)** charging a **Festo CRVZS-0,75** 0.75 L reservoir to **10 bar**. The downstream valve circuit below is unchanged, but the source swap is **not yet re-validated**. Two open items: the salvaged compressor needs its own over-pressure cutoff (current + temperature) since it lost the original electronics, and removing the low-pressure regulator is under consideration (redundant once the tank is capped at ≤10 bar — see the pressure note below and the safety-relief-valve task in `dv/tasks.md`).

The compressor keeps the tank topped up. Air passes the manual isolation valve and the regulator (capped at 10 bar), then splits at the NPFC-T into two parallel branches that recombine at the OR valve before reaching the actuator:

| Situation | EBS solenoid (normally-open) | VPPM proportional | Result at actuator |
|---|---|---|---|
| **Autonomous driving** (powered) | energised → supply blocked, its branch vents to atmosphere | regulates 0–10 bar on command | OR valve passes the **VPPM** pressure; the computer modulates braking |
| **Emergency / power loss** | de-energised → full tank pressure to its output | unpowered → all ports blocked | OR valve passes the **full EBS** pressure; the kart brakes hard |

The hardware is sponsored by **Festo** (see the [BOM](bom.md) for the donated parts).

## Why no isolation valve in series with the proportional valve

The obvious worry: when the EBS dumps full pressure into the actuator line during an emergency, could that air leak *out* through the proportional valve — backwards to the supply, or forwards to atmosphere through the VPPM's exhaust — and bleed away the braking force? An extra "ASB" solenoid in series ahead of the VPPM would block that path. We tested without it and it holds, for two independent reasons:

1. **The VPPM blocks itself when unpowered.** It is a 3/2-way *normally-closed* proportional regulator. On power loss the spring returns it to rest and **all three ports are isolated** — no supply path, no exhaust path. Festo's datasheet wording is "output pressure is maintained" (not vented). So pressure sitting at the VPPM's output cannot escape through it. (Full datasheet evidence below.)
2. **The OR valve already isolates the VPPM branch during an emergency.** The shuttle's ball is pushed by the higher-pressure side, sealing the lower-pressure side. When the EBS supplies full pressure, the ball seals off the VPPM branch, so emergency air never even reaches the VPPM.

Either mechanism alone would be enough; together they make a series isolation valve redundant. The physical test confirmed the actuator holds full pressure with no measurable loss through the VPPM, so the extra valve (its weight, cost, coil, and one more leak path) was removed.

## Why the OR / shuttle valve *is* required

The OR valve is **not** optional. During autonomous driving the EBS solenoid is energised, which connects its output to its exhaust — that branch is **open to atmosphere**. If the two branches were simply teed together, the pressure the VPPM is trying to regulate would pour straight out of the EBS's open exhaust and the brake would never build force.

The shuttle valve solves this: its ball always seals the lower-pressure (venting) inlet and passes the higher-pressure one to the actuator.

- **Driving:** VPPM side is pressurised, EBS side is venting → ball seals the EBS side → regulated pressure reaches the actuator.
- **Emergency:** EBS side is at full pressure, VPPM side is blocked → ball seals the VPPM side → full pressure reaches the actuator.

So the OR valve keeps the active branch from losing its air through the inactive branch's exhaust, in **both** directions of operation. That is the single reason it has to be there.

## VPPM unpowered behavior: the datasheet evidence

The VPPM analysis above hinges on one fact — that the valve blocks all ports when unpowered. Festo's datasheet calls this state "unregulated", which is ambiguous, so here is the evidence it actually means *all ports blocked, pressure trapped*.

**Sources:**

- Festo VPPM catalog documentation 205274 ([local](../../assets/datasheets/205274_documentation.pdf) | [online](https://www.festo.com/media/catalog/205274_documentation.pdf))
- Festo VPPM-8L-L-1-G14-0L10H-V1P-S1C1 datasheet, part 571293 ([local](../../assets/datasheets/VPPM_en.pdf) | [online](https://www.festo.com/us/en/a/571293/))

| Evidence | Location | Implication |
|---|---|---|
| Valve function: **"3-way proportional-pressure regulator, closed"** | 205274, page 2, "Valve function" table | The valve's default state is "closed" |
| Type code position 006: **"1 = 3/2-way valve, normally closed"** | 205274, page 4, type code table | Confirms the de-energized state is "closed" |
| **"Pressure is maintained if the controller fails"** | 205274, page 2, "Operationally safe" section | Output pressure does NOT vent to exhaust |
| **"Safety position VPPM: if the power supply cable is interrupted, output pressure is maintained unregulated."** | 571293 datasheet, page 1, "Safety instructions" row | No active regulation, but pressure is _maintained_ |
| Design: **"Piloted diaphragm regulator"** | Both datasheets | Piloted = a small solenoid controls a larger diaphragm |
| Type of reset: **"Mechanical spring"** | Both datasheets | Spring returns the diaphragm to its rest (closed) position |

**Interpretation.** The VPPM is a piloted diaphragm regulator with a mechanical spring return. When powered, its controller modulates the pilot to open/close the supply (1→2) and exhaust (2→3) paths. When power is lost: the pilot de-energizes, the spring returns the diaphragm to rest, and **all three ports are isolated**. "Maintained" is the key word:

- If port 2→3 (exhaust) were open, pressure would vent — it would *not* be maintained.
- If port 1→2 (supply) were open, pressure would *rise* to supply pressure, not just be maintained.
- "Maintained" means the pressure stays put, decaying only through slow natural seal leakage.

This is exactly the condition that lets us skip the series isolation valve.

## Component references

The diagram uses plain-English labels. Where possible we link to **local PDFs** in this repo; vendor links may require login or be blocked.

Terminology:

- `SDE5` is the Festo product family for our pressure sensors. The diagram calls them "Pressure sensor (tank side)" and "Pressure sensor (regulated side)".
- `NPFC-T` is a threaded T-adapter with 3× G1/4 female ports. Each port takes a CK-1/4 compression fitting.

| Component | Photo | Max pressure | BOM section | Local docs | Vendor link |
|---|---|---|---|---|---|
| Reservoir — Festo CRVZS-0,75 (160235) |  | **16 bar** rated (charged to 10) | [`Compressor & Tank`](bom.md#compressor-tank) | [`160235`](https://ftp.festo.com/Public/PNEUMATIC/SOFTWARE_SERVICE/DataSheet/EN_GB/160235.pdf) | [Festo](https://www.festo.com/us/en/a/160235/) |
| Compressor — salvaged portable inflator (motor + piston only) |  | ~10 bar target (being characterised) | [`Compressor & Tank`](bom.md#compressor-tank) |  | — |
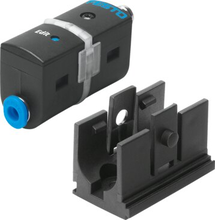
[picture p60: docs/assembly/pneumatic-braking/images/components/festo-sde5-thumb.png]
| Pressure sensor (tank side) |  | **10 bar** (measurement range) | [`Pressure Sensor 1`](bom.md#pressure-sensor-1-tank-side-before-regulator) | [`567465datasheet.pdf`](../../assets/datasheets/567465datasheet.pdf) | [Festo](https://www.festo.com/es/es/a/567465/) |
| Manual valve (release/isolation) |  | — | [`Manual Valve`](bom.md#manual-valve-brake-release-isolation) |  |  |
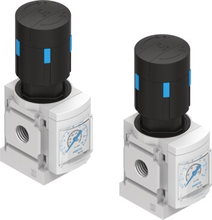
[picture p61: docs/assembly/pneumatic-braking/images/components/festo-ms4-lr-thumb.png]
| Pressure regulator (D7) |  | 0.5-12 bar output | [`Low-Pressure Regulator`](bom.md#low-pressure-regulator) | [`527690datasheet.pdf`](../../assets/datasheets/527690datasheet.pdf) | [Festo](https://www.festo.com/es/es/a/527690/) |
| Pressure sensor (regulated side) |  | **10 bar** (measurement range) | [`Pressure Sensor 2`](bom.md#pressure-sensor-2-regulated-side-before-valves) | [`567465datasheet.pdf`](../../assets/datasheets/567465datasheet.pdf) | [Festo](https://www.festo.com/es/es/a/567465/) |
| NPFC-T threaded T-adapter |  | — | [`Compression Fittings`](bom.md#compression-fittings) |  | [Festo](https://www.festo.com/es/es/a/8030236/) |
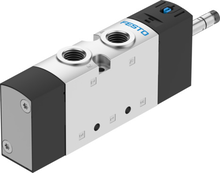
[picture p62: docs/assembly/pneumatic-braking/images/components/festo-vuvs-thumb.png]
| EBS solenoid valve (VUVS) |  | **10 bar** operating | [`EBS Electrovalve`](bom.md#ebs-electrovalve-emergency-braking) | [`575488datasheet.pdf`](../../assets/datasheets/575488datasheet.pdf) | [Festo](https://www.festo.com/es/es/a/8035174/) |
| OR / shuttle valve |  | — | [`Shuttle Valve`](bom.md#shuttle-valve-or-valve) |  | [Festo](https://www.festo.com/es/es/a/6682/) |
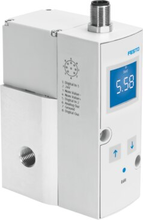
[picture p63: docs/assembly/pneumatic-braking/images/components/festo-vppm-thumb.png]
| ASB proportional valve (VPPM) |  | **11 bar** inlet | [`VPPM Proportional Valve`](bom.md#vppm-proportional-valve-asb) | [`205274_documentation.pdf`](../../assets/datasheets/205274_documentation.pdf), [`VPPM_en.pdf`](../../assets/datasheets/VPPM_en.pdf) | [Festo](https://www.festo.com/es/es/a/571293/) |
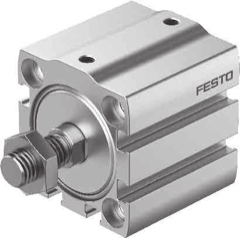
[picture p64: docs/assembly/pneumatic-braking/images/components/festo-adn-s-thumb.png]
| Brake actuator (ADN) |  | **10 bar** (50mm bore) | [`Pneumatic Actuator`](bom.md#pneumatic-actuator) | [`adn-s-enus.pdf`](../../assets/datasheets/adn-s-enus.pdf) | [Festo](https://www.festo.com/gb/en/a/8084714/) |
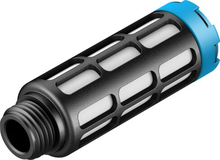
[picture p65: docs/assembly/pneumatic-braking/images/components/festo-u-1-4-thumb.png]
| Exhaust silencers (G1/4 + G1/8) |  | — | [`Silencers`](bom.md#silencers) | [`2316datasheet.pdf`](../../assets/datasheets/2316datasheet.pdf) | [Festo G1/4](https://www.festo.com/es/es/a/2316/), [Festo G1/8](https://www.festo.com/es/es/a/2307/) |
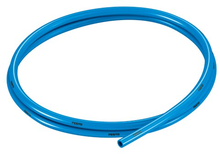
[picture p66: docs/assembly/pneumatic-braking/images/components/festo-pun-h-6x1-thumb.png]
| Tubing + fittings |  | 10 bar (tubing) | [`Tubing`](bom.md#tubing), [`Compression Fittings`](bom.md#compression-fittings) | [`197384datasheet.pdf`](../../assets/datasheets/197384datasheet.pdf), [`2029datasheet.pdf`](../../assets/datasheets/2029datasheet.pdf), [`4469datasheet.pdf`](../../assets/datasheets/4469datasheet.pdf) | Tubing: [Festo](https://www.festo.com/es/es/a/197384/), CK: [Festo](https://www.festo.com/es/es/a/2029/), NPFC-T: [Festo](https://www.festo.com/es/es/a/8030236/), LCK: [Festo](https://www.festo.com/es/es/a/4469/) |

> **Max system pressure: 10 bar.** The weakest downstream components (VUVS valve, SDE5 sensors, ADN-S actuator) are rated to 10 bar. The VPPM inlet accepts up to 11 bar. The D7 regulator can output up to 12 bar — **never set it above 10 bar** or downstream components may be damaged. The D6 variant only reaches 7 bar (too low); there is no MS4-LR variant capping at exactly 10 bar, so the D7 is necessary but requires care when adjusting.

### [Bill of Materials](bom.md)

---

## Historical archive

Two earlier candidate circuits — a super-simplified version (no OR valve, no ASB valve) and a full/conservative version (ASB valve **and** OR valve) — are kept with their diagrams on the [**Design History page**](design-history.md), along with why each was dropped in favour of the validated design (OR valve, no series ASB).

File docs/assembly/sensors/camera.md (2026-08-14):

<!-- Two gaps on this page are tracked in tasks.md, "Document the ZED2's published topics and the
     RViz2 cone-detection setup": (1) which ZED topics the stack consumes — the commented-out table
     further down was never corrected; (2) which packages to install to see cone detections in
     RViz2. -->

# ZED2 Camera Integration Documentation

## Overview

This document describes the integration of the **ZED2 stereo camera** into the kart and its usage through the **ROS 2 wrapper**.

Cone detection itself is not done by the camera — it is a separate ROS 2 node. This page covers getting images out of the ZED; what happens to them is on the [ROS 2 packages](../../software/ros2/packages.md#kart_perception) page.

## Official Resources

- **ZED2 Camera Overview**: [https://www.stereolabs.com/zed-2/](https://www.stereolabs.com/zed-2/)
- **ZED ROS 2 Wrapper Documentation**: [https://docs.stereolabs.com/ros2/](https://docs.stereolabs.com/ros2/)

## Hardware: ZED2 Camera

The [ZED2](https://www.stereolabs.com/zed-2/) camera by Stereolabs is a stereo vision camera capable of providing:

- High-definition left and right stereo images
- Depth sensing
- 3D point clouds
- Positional tracking (6DoF)
- Integrated IMU sensors (accelerometer, gyroscope, magnetometer)
- Environmental sensors (barometer, temperature sensor)

## ROS 2 Integration

The ZED2 camera is integrated into the project using the **official Stereolabs ZED ROS 2 Wrapper**:

- GitHub: [https://github.com/stereolabs/zed-ros2-wrapper](https://github.com/stereolabs/zed-ros2-wrapper)

### Installation Requirements

To properly install and run the **ZED ROS 2 Wrapper** with the ZED2 camera, you must ensure the following dependencies and system configuration are in place.

- Operating System

    - **Ubuntu 24.04 LTS** is the recommended version for this setup.
    - Other Ubuntu versions may be used; however, note that dependencies such as CUDA, TensorRT, ROS2, and the ZED SDK may require different versions and additional compatibility testing.

- ROS 2 Jazzy

    - Install **ROS 2 Jazzy** by following the official instructions here:  
  [https://docs.ros.org/en/jazzy/Installation/Ubuntu-Install-Debs.html](https://docs.ros.org/en/jazzy/Installation/Ubuntu-Install-Debs.html)

- CUDA Toolkit (12.0 to 12.9)

    - Install **CUDA 12.x** (any version from 12.0 to 12.9 is compatible).
    - Download from the official NVIDIA website:  
  [https://developer.nvidia.com/cuda-downloads](https://developer.nvidia.com/cuda-downloads)

- ZED SDK (v5.0)

    - Download and install **ZED SDK v5.0** for Ubuntu 24.04 with CUDA 12 and TensorRT 10 from the official release page:  
  [https://www.stereolabs.com/en-es/developers/release/5.0#82af3640d775](https://www.stereolabs.com/en-es/developers/release/5.0#82af3640d775)

- TensorRT 10

    - Download the **TensorRT 10** `.deb` package for Ubuntu 24.04 + CUDA 12.9 from the official NVIDIA repository:  
  [https://developer.nvidia.com/downloads/compute/machine-learning/tensorrt/10.10.0/local_repo/nv-tensorrt-local-repo-ubuntu2404-10.10.0-cuda-12.9_1.0-1_amd64.deb](https://developer.nvidia.com/downloads/compute/machine-learning/tensorrt/10.10.0/local_repo/nv-tensorrt-local-repo-ubuntu2404-10.10.0-cuda-12.9_1.0-1_amd64.deb)

    After downloading the `.deb` file, run the following commands to install it:

```bash
sudo dpkg -i nv-tensorrt-local-repo-ubuntu2404-10.10.0-cuda-12.9_1.0-1_amd64.deb
sudo apt update
```

If you encounter **GPG key errors**, follow these additional steps:

```bash
sudo cp /var/nv-tensorrt-local-repo-ubuntu2404-10.10.0-cuda-12.9/*.gpg /usr/share/keyrings/

sudo nano /etc/apt/sources.list.d/nv-tensorrt-local-repo-ubuntu2404-10.10.0-cuda-12.9.list
```

Replace the content of the file with:

```bash
deb [signed-by=/usr/share/keyrings/nv-tensorrt-local-CD20EDBE-keyring.gpg] file:///var/nv-tensorrt-local-repo-ubuntu2404-10.10.0-cuda-12.9 /
```

Then update again:

```bash
sudo apt update
```

This should resolve the key issues.

Finally, install the required TensorRT runtime libraries:

```bash
sudo apt-get install libnvinfer10 libnvinfer-dev libnvinfer-plugin-dev python3-libnvinfer
```

- ZED ROS 2 Wrapper

    - Clone and build the **zed-ros2-wrapper** package in your existing ROS 2 workspace:

```bash
cd ~/ros2_ws/src
git clone https://github.com/stereolabs/zed-ros2-wrapper.git
cd ..
rosdep install --from-paths src --ignore-src -r -y
colcon build --symlink-install
```

Official repository:  
[https://github.com/stereolabs/zed-ros2-wrapper](https://github.com/stereolabs/zed-ros2-wrapper)

---

Once all the dependencies are installed and the wrapper is successfully built, you should be able to launch the ZED2 ROS 2 node without issues.

### Launching the Camera

The camera is launched using a provided launch file, typically:

```bash
ros2 launch zed_wrapper zed_camera.launch.py camera_model:=zed2
```

<!-- ### Published Topics of Interest

CORREGIR POR TOPICS CORRECTOS

| Topic Name | Message Type | Description |
|---|---|---|
| `/zed2/zed_node/left/image_rect_color` | `sensor_msgs/Image` | Rectified color image from left camera |
| `/zed2/zed_node/depth/depth_registered`| `sensor_msgs/Image` | Depth image aligned to the left camera |
| `/zed2/zed_node/imu/data` | `sensor_msgs/Imu` | IMU data (accelerometer + gyroscope + orientation) |
| `/zed2/zed_node/point_cloud/cloud_registered` | `sensor_msgs/PointCloud2` | Registered 3D point cloud |
| `/zed2/zed_node/odom` | `nav_msgs/Odometry` | Visual odometry (pose estimation) | -->

## Where cone detection happens

There are two ways to detect cones from this camera, and the kart normally uses the first.

### 1. Our own YOLO node (default)

`kart_perception/yolo_detector_node.py` subscribes to the ZED's rectified RGB topic and runs **YOLOv11n** through Ultralytics at `imgsz` 320, with TensorRT `.engine` weights on the Orin. The ZED wrapper is left as a plain image source — its built-in object detection stays off. Launch it with `perception_3d.launch.py`.

This is the path that is tuned and tested: the detector's parameters, the weights files, and the 2D → 3D projection that follows are documented under [ROS 2 → Packages → kart_perception](../../software/ros2/packages.md#kart_perception).

### 2. The ZED SDK's built-in object detection (alternative)

The ZED wrapper can also run a custom detector itself, on the GPU, and publish `ObjectsStamped` with 3D positions already resolved — which removes our depth-projection step. `perception_zed_od.launch.py` runs the pipeline in this mode; it launches only the marker visualiser, because the detector and the depth localiser are not needed.

To enable it, export the model to ONNX and point the wrapper at it in `common_stereo.yaml` (in `zed-ros2-wrapper/zed_wrapper/config`):

```yaml
object_detection:
     od_enabled: true
     model: 'CUSTOM_YOLOLIKE_BOX_OBJECTS'
     custom_onnx_file: '<path to model>'
```

The first launch with a new ONNX file is slow — TensorRT optimises the model then, taking seconds to minutes depending on the machine. The optimised engine is cached, so later runs start quickly.

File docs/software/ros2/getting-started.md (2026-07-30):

# Getting Started

The kart software runs on **Ubuntu 22.04** with **ROS 2 Humble**. There are two deployment targets:

| | Simulation (development) | Real Hardware (on the kart) |
|---|---|---|
| **Machine** | Mac → UTM VM (Ubuntu 22.04 ARM64) | Jetson AGX Orin (Ubuntu 22.04 ARM64) |
| **Sensor** | Gazebo Fortress simulated RGBD camera | ZED stereo camera |
| **Perception** | Ground truth from SDF, or YOLO on simulated images | YOLO + depth projection |
| **Actuators** | Gazebo Ackermann plugin (`/kart/cmd_vel`) | ESP32 over USB serial (`/kart/cmd_vel` → `state_machine` → `/kart/cmd_vel_muxed` → `cmd_vel_bridge` → framed int32 protocol) |
| **GPU** | None (LLVMpipe software rendering) | NVIDIA GPU (CUDA for YOLO + ZED) |

Both targets produce the same `/perception/cones_3d` topic — a controller node works identically in either mode.

---

## 1. Simulation on Mac (via UTM VM)

### Prerequisites

Set up a UTM virtual machine running Ubuntu 22.04 ARM64 with at least 8 GB RAM and 4 CPU cores. Configure SSH access so you can reach it with `ssh utm` (or use the IP directly, typically `192.168.65.2`).

On the VM, install ROS 2 Humble:

```bash
# Follow https://docs.ros.org/en/humble/Installation/Ubuntu-Install-Debs.html
sudo apt install ros-humble-desktop
```

Install simulation dependencies:

```bash
sudo apt install \
  ros-humble-ros-gz \
  ros-humble-vision-msgs \
  ros-humble-xacro \
  ros-humble-tf2-ros \
  mesa-utils libegl1-mesa-dev libgles2-mesa-dev
```

`ros-humble-ros-gz` installs Gazebo Fortress and the ROS bridge (~3-4 GB).

### Clone & Build

```bash
ssh utm

cd ~
git clone https://github.com/UM-Driverless/kart-brain.git
source /opt/ros/humble/setup.bash
cd ~/kart-brain
colcon build
source install/setup.bash
```

!!! tip "Add to `.bashrc` for convenience"
    ```bash
    echo 'source /opt/ros/humble/setup.bash' >> ~/.bashrc
    echo 'source ~/kart-brain/install/setup.bash 2>/dev/null' >> ~/.bashrc
    echo 'export IGN_GAZEBO_RESOURCE_PATH=$(ros2 pkg prefix kart_sim 2>/dev/null)/share/kart_sim/models' >> ~/.bashrc
    ```

### Launch the Simulation

```bash
# Default: ground-truth perception (no YOLO, no camera needed)
ros2 launch kart_sim simulation.launch.py

# With YOLO vision pipeline (uses simulated camera images)
ros2 launch kart_sim simulation.launch.py use_yolo:=true
```

Default mode launches 5 processes:

1. **Gazebo server** — headless physics + OGRE2 rendering (LLVMpipe)
2. **ros_gz_bridge** — bridges Gazebo topics to ROS 2
3. **perfect_perception_node** — ground-truth cone detection from SDF
4. **cone_marker_viz_3d** — RViz marker visualization
5. **cone_follower_node** — midpoint-steering controller

With `use_yolo:=true`, it replaces perfect perception with:

- **camera_info_fix_node** — corrects Gazebo's wrong camera intrinsics
- **yolo_detector** — YOLOv11 inference on simulated images
- **cone_depth_localizer** — depth-based 2D→3D projection

### Verify it's working

In a second SSH terminal:

```bash
ssh utm

source /opt/ros/humble/setup.bash
source ~/kart-brain/install/setup.bash

# Check topics are active
ros2 topic list

# See cone detections
ros2 topic echo /perception/cones_3d --once

# See controller output
ros2 topic echo /kart/cmd_vel --once
```

### Visualize

**RViz** (via X11 forwarding):

```bash
ssh -X utm
rviz2
```

1. Set **Fixed Frame** to `odom`
2. Add **MarkerArray** → `/perception/cones_3d_markers`
3. Add **TF** to see the kart's position
4. Add **Odometry** → `/model/kart/odometry` for velocity arrows

**Foxglove Studio** (from Mac — best experience):

```bash
# On the VM
sudo apt install ros-humble-rosbridge-server
ros2 launch rosbridge_server rosbridge_websocket_launch.xml

# On Mac: open Foxglove Studio, connect to ws://192.168.65.2:9090
```

See [Simulation](simulation.md) for track layout, kart model specs, and troubleshooting.

---

## 2. Real Hardware on the Jetson Orin

### Prerequisites

Follow the **[Orin Setup Guide](../../assembly/electronics/orin-setup.md)** to flash the Orin and install all software (JetPack, CUDA, ROS 2, ZED SDK, PyTorch, kart-brain, remote access). That guide covers everything from a blank Orin to a fully configured system.

Once setup is complete, the kart-brain workspace is already built at `~/kart-brain`.

### Connect Hardware

Before launching, connect:

1. **ZED camera** — USB 3.0 port
2. **ESP32 (Kart Medulla)** — USB port (appears as `/dev/ttyACM0`; the S3's WCH CH343 bridge is a CDC-ACM device, not the retired classic board's `/dev/ttyUSB0`)
3. **Gamepad** — USB or Bluetooth

### Manual Driving (Teleop)

```bash
ros2 launch kart_bringup teleop.launch.py
```

Hold **R1** (deadman switch) and use **R2** for throttle, **L2** for brake, **left stick** for steering.

### Autonomous Perception

Start the ZED camera node, then launch the perception pipeline:

```bash
# Terminal 1: ZED camera
ros2 launch zed_wrapper zed_camera.launch.py camera_model:=zed2

# Terminal 2: Perception pipeline
ros2 launch kart_perception perception_3d.launch.py
```

This runs YOLO detection, depth-based 3D localization, and RViz visualization. The ZED provides correct camera intrinsics natively — no fix node needed (that's simulation-only).

Verify detections:

```bash
ros2 topic echo /perception/cones_3d --once
```

### Full Autonomous Stack

Once perception is running, start a controller node that subscribes to `/perception/cones_3d` and publishes `Twist` on `/kart/cmd_vel`. The `cone_follower_node` from kart_control does exactly this — it works identically in simulation and on real hardware.

---

## Rebuilding After Changes

```bash
# Rebuild everything (--symlink-install so Python/launch edits work without rebuilding)
cd ~/kart-brain && colcon build --symlink-install && source install/setup.bash

# Rebuild only the package you changed (faster)
colcon build --symlink-install --packages-select kart_sim && source install/setup.bash
```

!!! tip "Why `--symlink-install`?"
    With `--symlink-install`, Python scripts and launch files in `install/` are symlinks to `src/`. Edits take effect immediately — only C++ changes need a rebuild. **Always use this flag.**

!!! warning "Always re-source after building"
    After `colcon build`, you must run `source install/setup.bash` for the changes to take effect in your current terminal. New terminals that source it from `.bashrc` pick it up automatically.

## Useful Commands

```bash
# List all active topics
ros2 topic list

# See message rate
ros2 topic hz /perception/cones_3d

# Echo a topic (one message)
ros2 topic echo /kart/cmd_vel --once

# Publish a manual velocity command (simulation only)
ros2 topic pub /kart/cmd_vel geometry_msgs/msg/Twist \
  "{linear: {x: 2.0}, angular: {z: 0.0}}" -r 10

# List running nodes
ros2 node list

# Stop the simulation
pkill -9 ign; pkill -f parameter_bridge; pkill -f perfect_perception; pkill -f cone_follower
```

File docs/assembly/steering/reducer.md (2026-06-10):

# Steering Reducer

The salvage motor spins fast and weak; the steering column needs the opposite — slow and strong. The reducer trades the motor's cheap speed for torque. See [Sizing the actuator](index.md#sizing-the-actuator) for why (torque is heat-limited, speed is basically free) and the numbers (~8 Nm at the column, ~47 W, ~11:1 reduction).

## Why a planetary

We needed ~11:1 in a small, **coaxial** package, cheap enough to reprint when it breaks, and **backdrivable** (so the wheels still turn by hand if the electronics die). A planetary packs the whole reduction into one ring of gears around the shaft — coaxial and compact, load shared across the planets, and it stays backdrivable.

The other reducer types either don't backdrive (worm, ball-screw), can't be printed with any strength (harmonic flexspline), or sprawl across two axes (plain gear train). Full comparison and the two alternatives we're keeping live: **[Alternative reducer designs](alternatives/index.md)**.

The price of the planetary is that it's the **least forgiving of print error** — every planet has to mesh the sun *and* the ring simultaneously, so all the tolerances have to agree at once. That's the source of most of the failures below.

## Current design (~11:1, two stages)

| Stage | Type | Teeth | Module | Centre distance | Ratio |
|---|---|---|---|---|---|
| 1 — planetary | sun → 4 planets → fixed ring | sun 12, planet 16, ring 44 | 2 mm | 28 mm | 4.67 : 1 |
| 2 — output pair | pinion → big gear (to column) | pinion 13, gear 31 | 3 mm | 66 mm | 2.38 : 1 |
| **Total** | | | | | **≈ 11.1 : 1** |

All three planetary gears share **module 2 mm, 20° pressure angle**. The geometry isn't free: an internal planetary obeys `Z_ring = Z_sun + 2·Z_planet` (44 = 12 + 2·16), so fixing the ring at 44 and the sun at 12 **forces** the planet to 16 and the centre distance to `m·(Z_sun + Z_planet)/2 = 28 mm`. The ratio is `1 + Z_ring/Z_sun = 4.67` (fixed ring, sun input, carrier output).

The planetary was 5.4:1 with a 10-tooth sun; it dropped to 4.67:1 when the sun/planets moved to the **Norelem hub geometry** (12-tooth sun, off-the-shelf steel option). Full Fusion parameters live in the team's `kart/steering/` files (`planetary_reducer_parameters.md`, `output_pinion_parameters.md`).

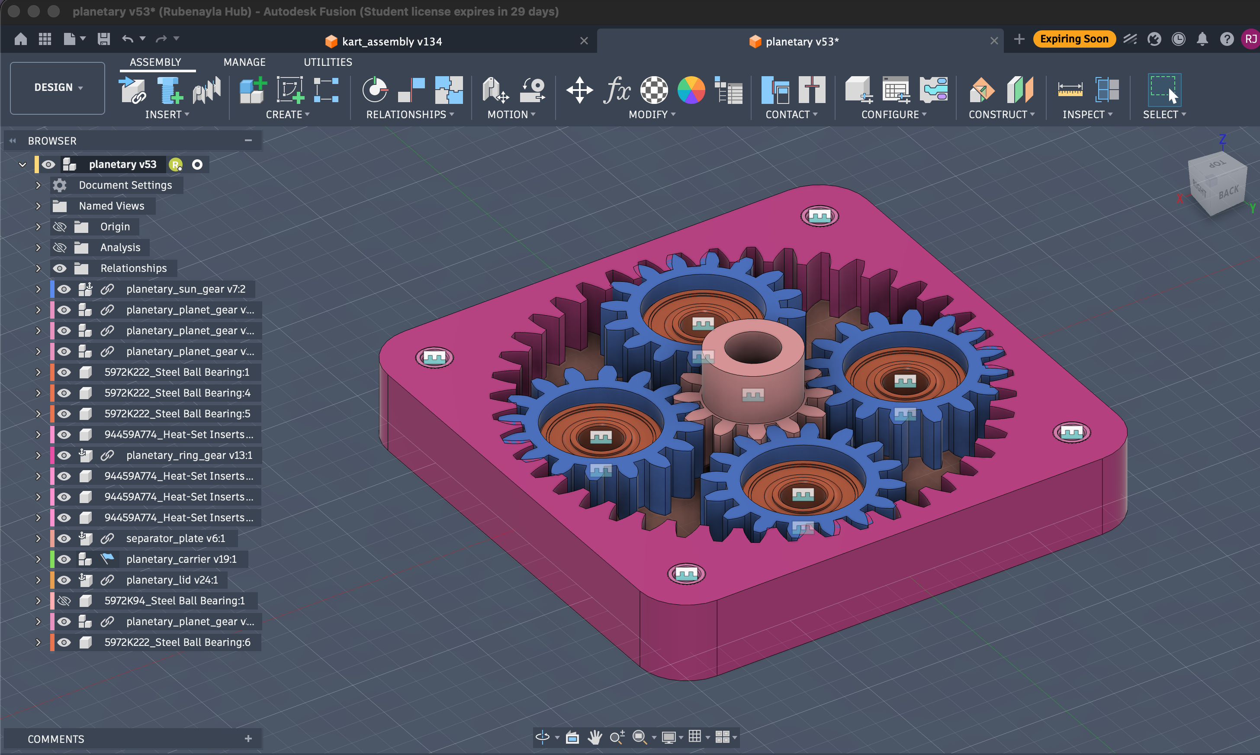
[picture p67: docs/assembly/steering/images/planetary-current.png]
Current Option-A planetary in Fusion 360 — 12-tooth sun, 4 planets, 44-tooth ring


*The current planetary (Fusion `planetary v53`): 12-tooth sun at centre, 4 planets, 44-tooth ring.*

The planets ride on the carrier (the output); the sun is the motor input and the ring is held fixed:

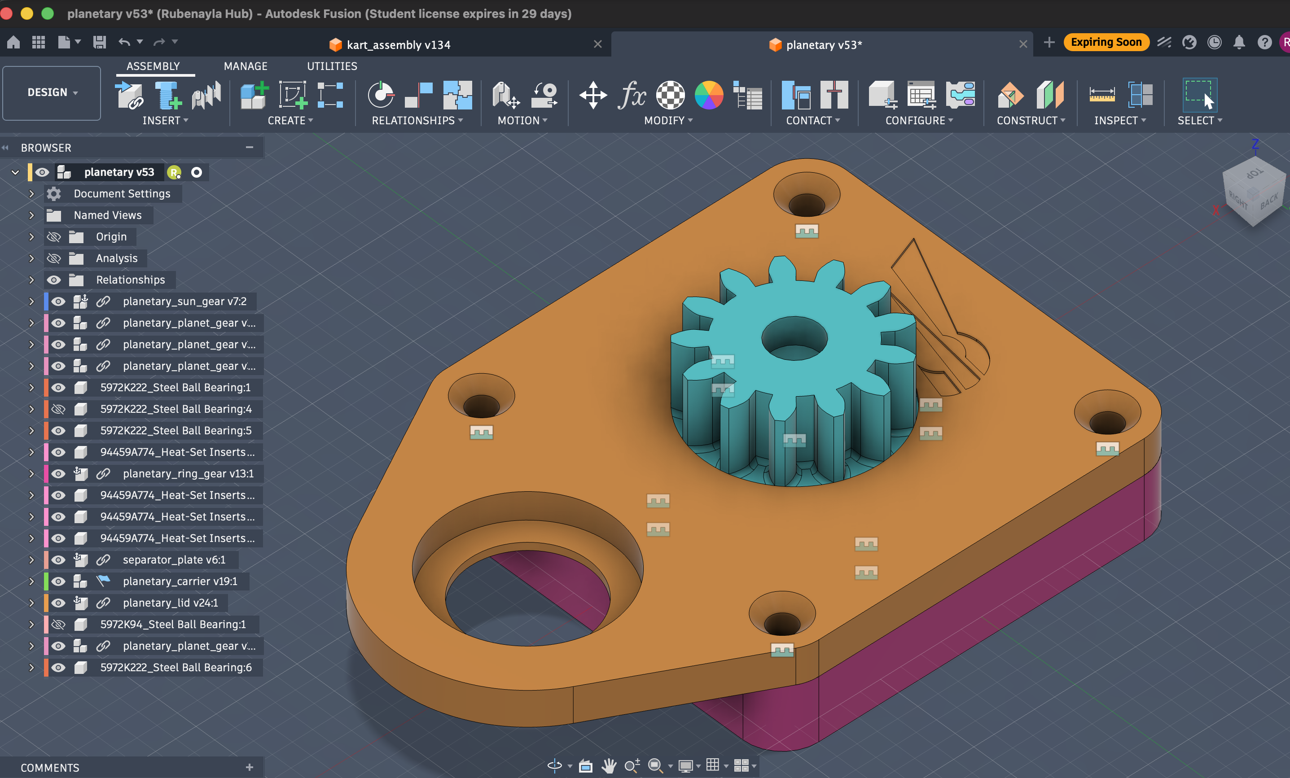
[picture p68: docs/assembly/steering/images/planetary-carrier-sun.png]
Planet carrier with the sun gear standing in it


*Carrier plate with the sun gear — the carrier clamps to the motor shaft and carries the four planets on steel ball bearings.*

### Gear generation

The gear tooth profiles are generated in Fusion 360 with the **[GF Gear Generator](https://apps.autodesk.com/FUSION/en/Detail/Index?id=1380101096547741187)** plugin, one part file per gear, referencing the shared module / teeth / pressure-angle parameters. Two gotchas worth knowing:

- The generator needs a **Hybrid Design** file type — Part Design refuses to add the gear component.
- The generated teeth are **static geometry**, not parametric — changing a tooth-count parameter does *not* re-cut the teeth. Each gear has to be **regenerated** when its tooth count changes (and the circular-pattern count is hard-set, so bumping the parameter alone leaves stale geometry — a trap that has bitten us). Promote module / teeth / face width to user parameters so downstream features still update.

## Gear materials — the real problem

Choosing a gear material isn't picking "the best" one; it's deciding **what to optimise** — every property trades against another:

> low friction ↔ creep resistance ↔ rigidity ↔ wear ↔ toughness (not brittle) ↔ printability ↔ cost

| Material | Why considered | Why it fell short |
|---|---|---|
| **PLA** | stiff, trivial to print | brittle → poor fatigue; teeth snap, gears split. Broke after 5 laps. Fine only for the big, low-stress gears. |
| **ABS** | tougher than PLA, more heat, easy + cheap | not slippery, still creeps — but with the steel sun taking the D-flat load, it's good enough. **This is the current printed material** for the planets and carrier. |
| **Nylon (PA)** | low friction, tough — the classic gear plastic | **creeps** under sustained load → the D-flat on the motor shaft rounds off and slips. Absorbs moisture. |
| **PPA** | aromatic-ring nylon: stiffer, far less creep, low moisture | the step up; harder + dimensionally stable, better wear under load. |
| **PPA-CF** | carbon adds stiffness | CF is abrasive (wears the steel it grips) and embrittles → can *worsen* the cracking it's meant to fix. Test before committing. |
| **Brass / steel** | the endgame for the part that matters | machined / off-the-shelf (Norelem hub sun); no plastic wins at the motor interface. |

### The root cause: the D-flat, not the gears

The real weak point is the **motor-shaft interface** — a D-flat + set screw in a creeping plastic. Fix the material *there* (brass / Norelem steel sun) and the root failure goes away regardless of what the rest is printed in. This is also why a [cycloidal drive](alternatives/cycloidal.md) wouldn't dodge it — its eccentric input mounts on the same D-flat.

### Failure modes seen

- **PLA** — brittle fracture: snapped teeth, gears split, within minutes of load.
- **Nylon** — D-flat creep (the flat rounds off → slip); teeth round off under sustained load.
- **Holder / carrier deformation** — the mount flexing under load lets the gears separate and skip; a failure path independent of the gears themselves.

!!! note "Status: still iterating"
    Six print generations in, it works — kind of. Current path: a **Norelem steel hub sun** for the D-flat (the real failure point), the planets and carrier printed in **ABS**, and watching the carrier stiffness. PPA / PPA-CF were weighed for the printed gears but not adopted — ABS is tough enough once the steel sun carries the D-flat load. Not solved.

## CAD

!!! info "CAD available on request"
    The reducer is fully modelled in Fusion 360 — the parametric design, a STEP, and print-ready gear STLs. We haven't published the files here yet, but we're happy to share them: if you'd like the CAD for your own build, [get in touch](../../contact.md).

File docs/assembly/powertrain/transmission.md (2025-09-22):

# Transmission System

## Current Configuration - 219 Kit

The kart currently uses a **standard 219 pitch karting transmission system**. This is the definitive configuration after testing and discarding the original T8F kit that came with the motor.

### Components

#### Chain

??? example "View gold 219 chain installed on the kart"
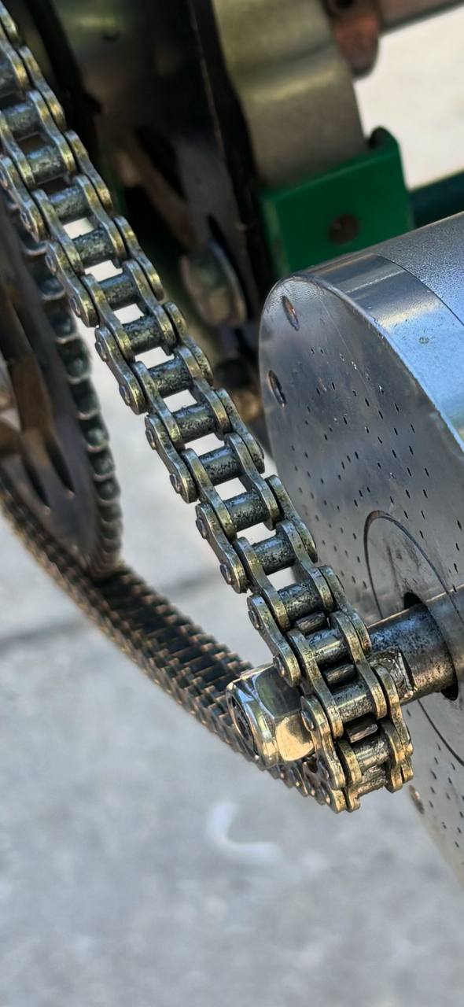
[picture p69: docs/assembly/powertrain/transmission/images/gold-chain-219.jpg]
Gold 219 chain installed on the kart
    

- **Type:** IRIS 219 pitch chain
- **Color:** Gold
- **Length:** 100 links
- **Status:** Installed and working
- **Purchase link:** <a href="https://kpsracing.es/cadenas-y-cubrecadenas/2434-649-cadena-iris-219.html#/254-numero_pasos_cadena-100" target="_blank">IRIS 219 Chain at KPS Racing</a>

#### Rear Sprocket (Corona)
- **Type:** Aluminum 219 pitch sprocket
- **Color:** Black anodized
- **Teeth:** *(Check sprocket for exact number)*
- **Status:** **Damaged - needs replacement** (~20€)
- **Damage cause:** Used incorrectly with T8F chain (incompatible pitch)
- **Replacement link:** <a href="https://kpsracing.es/coronas/5957-9775-corona-aluminio-219-negra.html" target="_blank">219 Aluminum Sprocket at KPS Racing</a>

#### Front Sprocket (Piñón)
- **Type:** Custom 219 pitch sprocket
- **Manufacturing:** Laser cut (custom design)
- **Material:** Steel
- **Teeth:** Multiple options manufactured with different tooth counts
- **Special features:** Custom design for non-standard Chinese motor shaft

---

## About chain pitch standards

The karting industry primarily uses three chain pitch standards:

1. **#219** - Standard karting chain (7.774mm pitch)
2. **#35**  - Smaller chain used in some mini karts (9.525mm pitch)
3. **#428** - Larger chain used in heavy-duty karts (12.7mm pitch)

The kart currently uses the **#219** standard, which is the most common for 2-stroke racing karts. We made this choice because:

- It is widely available and supported in the karting community.
- It offers a good balance of strength, weight, and size for our kart.
- It is compatible with the sprockets we can source or manufacture.
- It allows for easy future upgrades or changes to the drivetrain.
- It was the closest match to the motor's original transmission kit. Initially, we thought that maybe the difference in pitch between T8F and 219 was negligible and we might avoid design any part, but after testing we found that it was not the case.

> **Note:** The original T8F kit that came with the motor is not a standard karting pitch and has been discarded in favor of the #219 system. However, as a temporary measure, part of the original T8F kit was used to get the kart moving initially, since we knew the switch to #219 would take some time due to sourcing parts and manufacturing the custom front sprocket. In this process, the rear sprocket was damaged due to the incompatible chain pitch, and it needs to be replaced.

## Why did you discard the T8F kit?

The T8F kit was not suitable for long-term use because is not a standard karting pitch, making it hard to find compatible parts locally. One of the requirements we established early on was to use components that could be easily sourced or replaced in case of failure, since **this kart was never intended to complex hardware development but software development**. Having a non-standard pitch would complicate maintenance and repairs, especially in a development environment where quick and cheap fixes are often needed due to failures or changes.

## Why Custom Front Sprocket?

The motor we purchased (Kunray MY1020) comes with a non-standard shaft configuration:

- **Shaft diameter:** 10mm
- **Keyway:** None
- **Length:** Very short

This is a 1:1 representation of the shaft configuration of the motor we purchased:
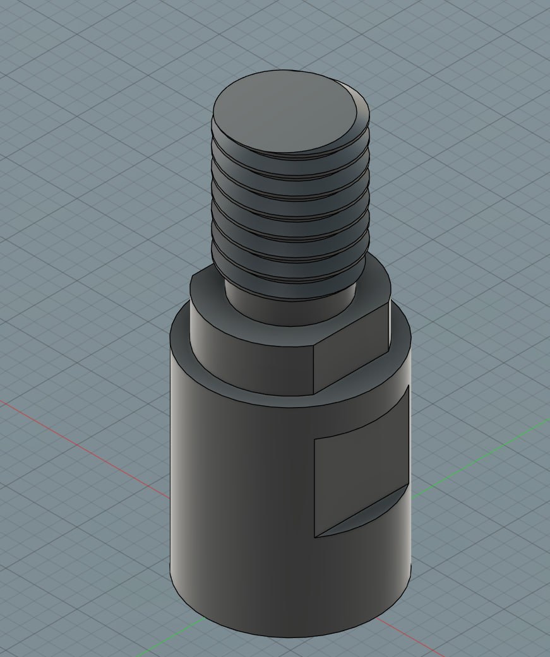
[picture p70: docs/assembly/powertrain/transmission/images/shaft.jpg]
Motor shaft configuration


The rear sprocket in the T8F kit could not be mounted on the kart's axle easily. There are standard sprocket mounting options for a wide range of both kart axles and rear sprockets, but since T8F is not a standard karting pitch, we could not find a compatible rear sprocket mount that would fit our kart axle right away. Design and manufacturing of a custom rear sprocket mount was considered too complex and expensive for our needs, as well as time consuming. Knowing that we would eventually switch to a standard karting pitch, we decided to discard the T8F kit entirely.

You can see here both the price and images of the rear sprocket mount we actually mounted: [219 Rear Sprocket Mount - 40mm Axle](https://kpsracing.es/portacoronas-y-portadiscos/3386-portacorona-40mm-tipo-219.html). Its mounting holes do not match the original T8F rear sprocket mounting holes. We would have to design a custom rear sprocket mount if we wanted to keep using the T8F kit. This is why we discarded the T8F kit entirely.

However, since the motor shaft was either not standard on karting motors, or at least not compatible with standard karting sprockets, we were forced to design and manufacture a custom front sprocket that would fit the motor shaft while maintaining the 219 pitch for chain compatibility. Contrary to the rear sprocket, the front sprocket is much simpler to design and manufacture, as it only needs to fit the motor shaft securely. This was done via laser cutting service for a minimal cost. In fact, it was as easy as replicating the inner geometry of the original T8F front sprocket, which was designed to fit the motor shaft, and then adapting the outer geometry to match the #219 pitch standard. A matter of hours of CAD work and a few iterations to get the tooth count right.

Here you can see a cross section of both the [simplest #219 front sprocket](https://kpsracing.es/pinones-motor/2280-425-pinon-tipo-iame-20mm.html#/92-talla-10z) we could find and the motor shaft, before deciding to design a custom sprocket:
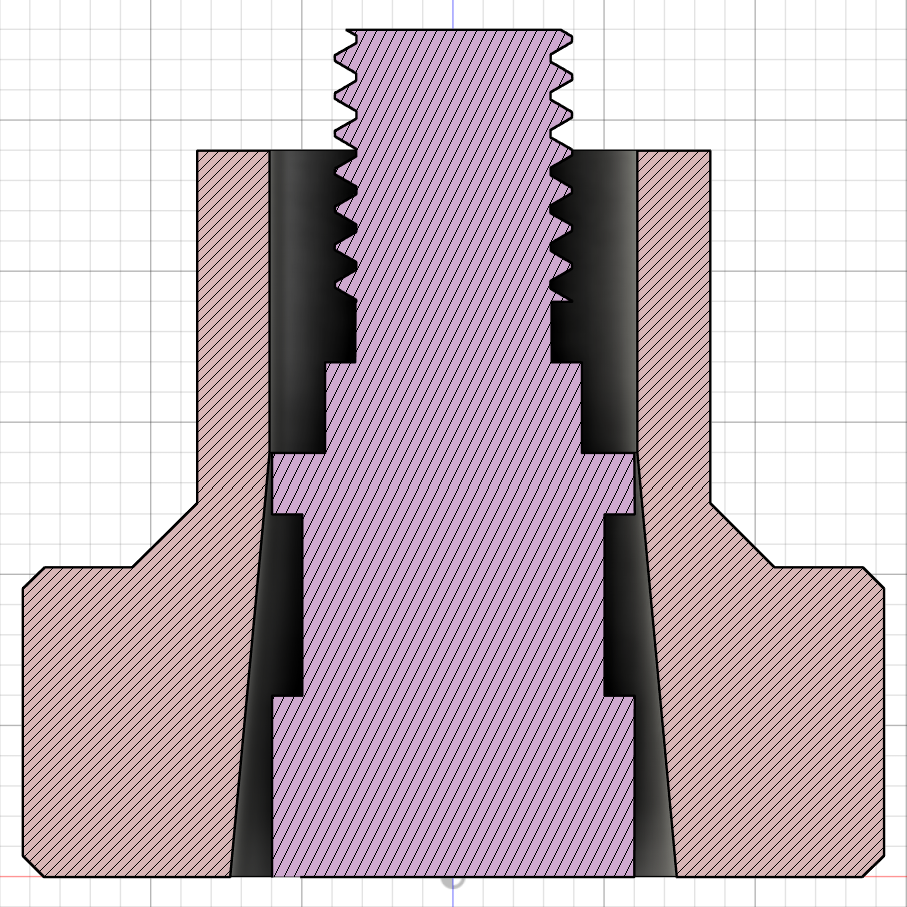
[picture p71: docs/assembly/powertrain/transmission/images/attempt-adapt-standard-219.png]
Attempt to adapt standard 219 sprocket to motor shaft


There was no way to adapt this standard sprocket to the motor shaft without extensive machining, which would have been more expensive than simply designing and manufacturing a custom sprocket.

> The custom sprocket design was completed and validated (3D printed) in January 2025 and manufactured via laser cutting service for a minimal cost in May 2025. However, due to laser cutting limitations, teeth are not chamfered, which may affect chain engagement slightly. This can be improved in future iterations by using CNC machining, which can produce more precise and durable sprockets. For now, the laser-cut sprocket is sufficient for testing and development purposes if we are careful with chain tensioning and alignment.

---

## Discarded T8F Kit

The motor originally came with a T8F transmission kit:

- **Chain:** Black T8F chain
- **Rear sprocket:** Black T8F sprocket (never used)
- **Front sprocket:** Black T8F 11-tooth sprocket

This kit was never intended for permanent use because as discused before, T8F is not a standard karting pitch. However, some components were temporarily used to get the kart moving while waiting for the 219 chain and custom front sprocket to arrive.

We have damaged knowingly the rear sprocket by using it with the incompatible T8F chain and front sprocket, which is why we need to replace it. Both chain and front sprocket are already replaced with the #219 equivalents.

**⚠️ These T8F components should be stored separately or discarded to avoid confusion.**

---

??? info "What do 219 and T8F mean? (Technical Details)"

    ### Chain Designation Explained

    **219 Chain**
    - Standard karting chain designation
    - Pitch: 7.774mm (0.306")
    - Roller diameter: 4.59mm
    - Originally invented as timing chain for Kawasaki motorcycles
    - European/Japanese standard for 2-stroke karting
    - Does NOT follow standard ANSI numbering formula

    **T8F Chain**
    - "T" = Chain type designation
    - "8" = 8mm pitch
    - "F" = Manufacturer designation
    - Pitch: 8.000mm
    - Roller diameter: 4.7mm
    - Common in Chinese electric scooters and pocket bikes
    - Also known as 05B chain

    ### What is "Pitch"?

    The **pitch** is the distance between the centers of two consecutive chain rollers. It's the most critical measurement for chain compatibility.

    ### Typical Usage

    - **219**: Professional karting standard, especially 2-stroke racing in Europe and Japan
    - **T8F**: Electric scooters, pocket bikes, and electric mobility devices (mainly Chinese market)

---

## Installation Notes

With the motor mount moved slightly backward (compared to the original 3D-printed mount), there is now sufficient clearance to properly install and tension the #219 chain.

### Correct Configuration Checklist

- Gold 219 chain installed
- 219 rear sprocket mounted (replace damaged one first)
- Custom 219 front sprocket mounted
- Proper chain tension adjusted
- All T8F components removed from work area

---

## Future Improvements

- Document exact tooth counts for ratio calculations
- Add chain tensioning procedure
- Include maintenance schedule
- Calculate speed/torque ratios for different sprocket combinations

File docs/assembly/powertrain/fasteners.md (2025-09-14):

# Powertrain Fasteners

## Overview

This page documents all fasteners (bolts, nuts, washers) used in the powertrain assembly. Each fastener is identified by location, size, and purpose with reference photos showing exact positions.

!!! warning "Critical Safety"
    Proper torque specifications must be followed. Loose motor mounts or sprocket bolts can cause catastrophic failure.

## Motor Mounting Hardware

### Motor to Chassis Mount
- **Location**: Motor mount bracket to chassis
- **Fasteners**: 4x M8x30 hex head cap screws with M8 nuts
- **Torque**: 25 Nm
- **Notes**: Use threadlocker on bolts. Check tension after first 10 hours of operation.

??? example "View motor mounting bolts"
    <!-- TODO: Add photo of motor mount bolt locations -->
    Motor mount bolt photo needed

## Transmission Hardware

### Front Sprocket (Motor Shaft)
- **Location**: Custom sprocket to motor shaft
- **Fasteners**: 3x M6x16 hex head cap screws
- **Torque**: 12 Nm
- **Notes**: Evenly spaced around sprocket. Use threadlocker.

### Chain Tensioning
- **Location**: Chain tensioner mechanism
- **Fasteners**: 2x M6x20 hex head cap screws
- **Torque**: 10 Nm
- **Notes**: Allows chain tension adjustment. Check weekly.

??? example "View transmission fasteners"
    <!-- TODO: Add photo of transmission bolt locations -->
    Transmission bolt photo needed

## Throttle Pedal Hardware

### Pedal Mount
- **Location**: Throttle pedal to floor plate
- **Fasteners**: 2x M5x12 hex head cap screws
- **Torque**: 6 Nm
- **Notes**: Ensure pedal is level and secure

## Assembly Instructions

### Installation Order
1. **Motor mount bolts**: Install motor to chassis first
2. **Front sprocket**: Attach custom sprocket to motor shaft
3. **Rear sprocket**: Mount to axle (see chassis fasteners)
4. **Chain**: Install and tension using tensioner hardware
5. **Throttle pedal**: Mount to accessible floor location

### Torque Sequence
- Always torque in cross pattern for multi-bolt connections
- Use threadlocker (blue, medium strength) on all critical bolts
- Re-check torque after first operation session

## Maintenance Schedule

| Component | Check Frequency | Action |
|---|---|---|
| Motor mount bolts | Weekly | Visual inspection, retorque if loose |
| Sprocket bolts | Bi-weekly | Check for looseness, clean threads |
| Chain tensioner | Weekly | Adjust tension, lubricate threads |
| Throttle mount | Monthly | Check for wear, ensure secure |

## Procurement

### Recommended Suppliers
- **McMaster-Carr**: High-quality metric fasteners
- **Bossard**: Professional fastener distributor
- **Local hardware**: Basic bolts and nuts

### Standard Materials
- **Steel, zinc plated**: Standard for most applications
- **Stainless steel**: For exposed locations (optional upgrade)
- **Threadlocker**: Loctite 243 (blue, medium strength)

## Total Fastener Cost
- **Estimated cost**: €8.50 for complete powertrain fastener kit
- **Recommended**: Purchase 25% extra for spares and maintenance

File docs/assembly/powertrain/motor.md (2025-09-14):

# Powertrain

## Motor

We use a **Brushless DC (BLDC) motor** from [Kunray](https://kunraymotors.com/shop/) (model **MY1020**, 72V 3000W), along with its supplied controller.  
The motivation for selecting an electric motor over a combustion engine is discussed in the [FAQ](../../faq.md#motor-choice).

---

## Motor Specifications

- **Type:** High-speed BLDC motor (Brushless DC)
- **Model:** Kunray MY1020
- **Nominal voltage:** 48VDC *(?)*
- **Nominal power:** 2000W–2500W *(?)*
- **Nominal current:** *(?)*
- **Rated speed:** *(?)*
- **Max speed:** *(?)*
- **Max torque:** *(?)*
- **Material:** Aluminum housing, full copper winding
- **Weight:** ~8 kg
- **Dimensions:** ~16.9 cm length x 9.6 cm height
- **Shaft:** 10mm diameter, no keyway (non-standard)
- **Product link (Amazon):** <a href="https://www.amazon.es/dp/B0C6WXYZ/ref=cm_sw_em_r_mt_dp_xyz" target="_blank">Kunray 72V 3000W Motor Kit</a>

> **Note:** For transmission system details (chain, sprockets), see [Transmission](transmission.md)

---

## Controller Specifications

- **Input voltage:** 48V *(?)*
- **Max current:** *(?)*
- **Max supported power:** *(?)*
- **MOSFETs:** *(?)*
- **Phase angle:** *(?)*
- **Undervoltage protection:** *(?)*
- **Built-in features:**
  - Reverse mode
  - PWM speed control
  - Three speed modes (low/medium/high)
  - High/low-level braking input
  - Hall sensor support
  - Sensorless mode supported
  - Ignition lock (anti-theft)
  - Cruise control
  - Soft start
  - Twist-grip throttle control
- **Product link (AliExpress):** [Kunray BLDC Controller 72V](https://www.aliexpress.com/item/...)

---

## Throttle Pedal Sensor

The throttle pedal sensor has the following wire assignments:

- **Red:** Vcc  
- **Yellow:** Ground  
- **Green/Blue:** Signal  

The twist-grip throttle that comes with the motor kit also includes:

- **Voltage range:** 12V–72V  
- **Functions:** Throttle signal, 3-speed selector, reverse mode  
- **Cable length:** ~1.5 m  
- **Material:** Rubber + ABS  

---

## Assembly

*This section will include real photos of the kart assembly taken from OwnCloud.*

>  **Important:** During the first installation, the **red steering part** was mounted in the wrong orientation. Refer to these pictures to ensure correct assembly in future setups.

*(Insert images here once available)*

---

## To be added:

- Full wiring table (cable color, pin name, voltage, function)
- Integration with control system (e.g., microcontroller / bluepill)
- DAC details (used to convert PWM signal if applicable)

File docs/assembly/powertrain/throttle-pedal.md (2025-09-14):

# Throttle Pedal Sensor

## Overview

The throttle pedal sensor uses a linear Hall effect sensor (typically SS49E or similar) that converts pedal position into an electrical signal for motor speed control.

## Common Hall Sensor Specifications

### SS49E Linear Hall-Effect Sensor
- **Manufacturer:** Honeywell / Various
- **Type:** Bipolar linear Hall effect sensor
- **Operating Voltage:** 2.7V to 6.5V DC (typically 5V)
- **Current Consumption:** ~6mA at 5V
- **Sensitivity:** 1.4-1.8 mV/Gauss
- **Output Type:** Ratiometric analog voltage
- **Null Output:** VCC/2 (2.5V at 5V supply with no magnetic field)
- **Output Range:**
  - ~0.86V with north pole magnetic field
  - ~2.5V with no magnetic field
  - ~4.2V with south pole magnetic field
- **Operating Temperature:** -40°C to +85°C (up to +150°C for some variants)
- **Package:** TO-92 (3-pin)
- **Datasheet:** [Honeywell SS49E](https://prod-edam.honeywell.com/content/dam/honeywell-edam/sps/siot/ja/products/sensors/magnetic-sensors/linear-and-angle-sensor-ics/common/documents/sps-siot-ss39et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)

## Pedal Assembly Specifications

- **Output Range (configured):**
  - 0-1V = 0% throttle (pedal released)
  - 4-5V = 100% throttle (pedal fully pressed)
- **Connector:** 3-wire cable
- **Mechanical:** Spring-return foot pedal with integrated magnet

## Product Sources

### Complete Pedal Assembly
- **AliExpress:** <a href="https://es.aliexpress.com/item/1005007243711390.html" target="_blank">Foot Pedal Accelerator (~2.46€)</a>
- **Amazon:** Various electric scooter throttle pedal listings

### Replacement Hall Sensors (SS49E)
- **Honeywell (Official):** <a href="https://www.mouser.com/ProductDetail/Honeywell/SS49E" target="_blank">Mouser Electronics - SS49E</a>
- **Addicore:** <a href="https://www.addicore.com/products/ss49e-linear-hall-effect-sensor" target="_blank">SS49E Linear Hall-Effect Sensor</a>
- **eBay:** <a href="https://www.ebay.com/itm/281782377861" target="_blank">5x SS49E Hall Sensors for Throttle Repair</a>
- **Sunrom Electronics:** <a href="https://www.sunrom.com/p/ss49e-hall-sensor-linear-analog" target="_blank">SS49E Hall Sensor Linear Analog</a>

!!! note "Replacement Parts"
    SS49E sensors commonly fail and typically need replacement yearly in high-use applications. Having spare sensors available is recommended for maintenance.

## Wiring

### Cable Color Code

| Cable Color | Function | Voltage |
|---|---|---|
| Red | Vcc | 5V |
| Yellow | Ground | GND |
| Teal (Green/Blue) | Signal | 0-5V |

!!! info "Signal Output"
    The sensor outputs a linear voltage proportional to pedal position:
    - Pedal released: 0V
    - Pedal fully pressed: 5V
    - The signal can be read by any ADC (Analog-to-Digital Converter) input

## Installation Notes

- Mount the pedal securely to prevent movement during operation
- Ensure cable is properly routed to avoid interference with pedal movement
- Protect connections from moisture and dirt
- Test full range of motion before use
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

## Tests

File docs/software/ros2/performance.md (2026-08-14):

# Performance & Latency

This page documents the end-to-end latency of the autonomous pipeline, what causes slowness at each stage, and the design decisions made to minimize it.

## End-to-end pipeline

The autonomous loop has six stages from photon to actuator:

```
ZED Camera → YOLO Detector → Cone Depth Localizer → Controller → Serial Bridge → ESP32
  ~33 ms       ~?? ms            ~?? ms              ~2 ms        ~5 ms         ~2 ms
```

!!! warning "Latency values are estimates"
    Most values on this page have NOT been measured on hardware yet. They are order-of-magnitude estimates based on code analysis. Actual profiling is needed — see [What we still need to measure](#what-we-still-need-to-measure).

## Stage-by-stage breakdown

### 1. Camera acquisition (~33 ms)

The ZED 2 captures stereo RGB + depth at up to 30 Hz (33 ms per frame). This is the fastest the pipeline can possibly run — everything downstream is bounded by camera FPS.

The ZED SDK does stereo matching (disparity → depth) on-board, so the depth image arrives alongside RGB with no extra ROS-side computation.

### 2. YOLO inference (not yet measured)

YOLOv11n runs on each RGB frame to detect cones. This is likely the **largest single latency contributor** in the pipeline.

**What `rclpy.spin()` is and why it matters:**
`spin()` is just an infinite loop that waits for ROS messages and calls callbacks one at a time:

```python
# Pseudocode for rclpy.spin()
while running:
    msg = wait_for_next_event()
    call_matching_callback(msg)  # blocks until callback returns
```

If YOLO inference ran directly inside the image callback, `spin()` couldn't receive new frames until inference finished. With queue depth=1 (keep-latest), frames arriving during inference would overwrite each other, but the queue slot itself can't be read until the callback returns. So the frame being processed would always be stale by one inference cycle.

**Our fix — dedicated inference thread:**
The ROS callback (`_on_image`) just stashes the latest frame behind a lock and returns immediately (~nanoseconds). A separate thread runs inference in a loop, always grabbing the most recent frame when it's ready for the next one.

```python
# ROS callback (runs in spin thread) — instant
def _on_image(self, msg):
    frame = self.bridge.imgmsg_to_cv2(msg, "bgr8")
    with self._frame_lock:          # lock held for ~nanoseconds (pointer swap)
        self._latest_frame = (msg.header, frame)
    self._frame_event.set()

# Inference thread (runs independently)
def _inference_loop(self):
    while not self._shutdown:
        self._frame_event.wait()
        self._frame_event.clear()
        with self._frame_lock:
            data = self._latest_frame
        # YOLO inference on data (~tens of ms)
```

This doesn't make inference faster (still one frame at a time), but it ensures:

- The frame being inferred is always the **freshest** one, not one that waited in the queue during the previous inference.
- The `spin()` loop stays responsive for any future callbacks (IMU, lidar, etc.).
- Lock contention is negligible — the lock only protects a Python reference swap, not a data copy.

**Queue depth = 1** on the image subscription means ROS keeps only the latest frame. Combined with the threading model, old frames are discarded at every level — we never process stale data.

### 3. Cone depth localizer (potentially high)

This node synchronizes three topics using `ApproximateTimeSynchronizer`:

- `/perception/cones_2d` (from YOLO)
- `/zed/.../depth/depth_registered` (from ZED)
- `/zed/.../rgb/camera_info` (from ZED)

The sync waits until it has messages from all three topics with timestamps within `sync_slop` of each other (default: **2.0 seconds**). The actual processing (median depth lookup + 3D projection) is fast (~5 ms), but the sync waiting can add variable latency depending on timestamp alignment.

!!! note "Is the 2.0s slop too large?"
    2.0 seconds is very conservative. If the ZED publishes RGB, depth, and camera_info in lockstep (which it should), timestamps should align within a few milliseconds. A tighter slop (0.1–0.2s) would reduce worst-case latency without dropping valid sync pairs. This needs profiling to confirm.

### 4. Controller (~2 ms)

`cone_follower_node` runs simple geometry (nearest blue+yellow cone → midpoint → `atan2` → steering angle) or a small neural net (17→16→2, 322 parameters). Either path completes in ~1–2 ms. Not a bottleneck.

A safety timer checks every 100 ms whether cones have been seen in the last second. If not, it publishes zero velocity (stop).

### 5. Serial bridge (~5 ms)

`cmd_vel_bridge` polls `/kart/cmd_vel_muxed` at 100 Hz (10 ms timer) and encodes the framed int32 binary messages for throttle, brake, and steering (see [Packages → kb_coms_micro](packages.md#kb_coms_micro)). `KB_Coms_micro` pushes these onto a TX thread queue and sends them over UART at 115200 baud.

A single frame is typically 8–15 bytes → **~1 ms on the wire** at 115200 baud. The TX thread wakes on a condition variable, so the queue-to-wire delay is near-instant.

### 6. ESP32 control loop (~2 ms)

The ESP32 runs its PID steering loop at **500 Hz** (2 ms period, `main/main.c`). When a new steering target arrives, it takes effect on the next PID cycle, so the worst-case wait is ~2 ms. Either way this stage is a rounding error in the pipeline, not the tail.

500 Hz is measured on the kart, not just the configured period: the firmware's `control_iters` counter advances by exactly 25 between consecutive 20 Hz telemetry frames. Nothing in the loop blocks — the MT6701 steering angle arrives as a PWM signal decoded by a hardware capture peripheral, and the loop reads the newest decoded frame from memory. What caps the rate is UART bandwidth, not the sensor: the per-cycle steering feedback frame uses about 87 % of the 115200-baud link, and transmission is unbuffered.

## QoS and queue depths

| Node | Topic | Queue depth | Notes |
|---|---|---|---|
| yolo_detector | image input | **1** | Keep-latest, drop old frames |
| yolo_detector | detections output | 10 | |
| cone_depth_localizer | sync buffer | 30 | ApproximateTimeSynchronizer internal buffer |
| cone_follower | cones_3d input | 10 | |
| cmd_vel_bridge | cmd_vel input | 10 | Polled at 100 Hz |
| KB_Coms_micro | all topics | 10 | |

All topics use default QoS (RELIABLE + VOLATILE) except odometry which uses BEST_EFFORT + VOLATILE.

## What we still need to measure

These are the key unknowns that require on-hardware profiling:

- [ ] **YOLO inference time** on the Orin GPU (YOLOv11n at 320 px — `imgsz` default is 320, weights `ruben_yolov11n_2026_03_320`). The node already logs FPS every 2 seconds to `/perception/yolo/fps` — run the pipeline and read it.
- [ ] **Actual sync delay** in `cone_depth_localizer` — log timestamp deltas between the three synced topics to see if 2.0s slop is causing unnecessary buffering.
- [ ] **End-to-end latency** from camera frame timestamp to ESP32 PWM output. Could be measured by comparing the image header timestamp with the time the corresponding steering command arrives at the ESP32.
- [ ] **Camera FPS** under load — does ZED maintain 30 Hz when the Orin GPU is busy with YOLO?
- [ ] **ESP32 control loop jitter** — `control_iters` shows the loop hitting its nominal 500 Hz, but not how much cycle-to-cycle jitter the blocking UART write adds. Worth measuring before anyone tries to raise the rate.

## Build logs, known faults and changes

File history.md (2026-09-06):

<!-- consult selectively — grep, never read in full -->

# History

Append-only log of notable decisions and events for `kart-docs`. Chronological (oldest first), append at the end.

---

## 2026-04-13 — Kart Medulla MCU: classic ESP32 → ESP32-S3 (docs reframed)

**Decision.** The next revision of the Kart Medulla interface PCB targets the **ESP32-S3** (ESP32-S3-WROOM-1 module). The classic ESP32 (ESP32-WROOM-32 on a DevKitC V4) is retired as the target MCU for new hardware.

**Status at decision time.** No Kart Medulla PCB has been manufactured. The classic ESP32 is currently hand-wired directly in the kart for basic functionality — this continues to be the operational setup until the S3 PCB is built and flashed.

**Why.**

- **Pin count.** The classic ESP32 ran out of usable GPIOs once CAN, SPI, status RGB, buzzer, and the Orin link were added on top of 3× halls, 3× pressure, accelerator, brake, SDC, steering, and relay. Too many classic-ESP32 GPIOs are reserved for flash/SDIO or are strap-pin traps. The S3 offers ~45 usable GPIOs.
- **Native USB-OTG.** Orin link moves from UART (through an external USB-UART bridge chip) to direct USB CDC-ACM — drops a BOM item, raises throughput from ~1 Mbit/s to ~12 Mbit/s full-speed USB, and gives hot-plug handling for free.
- **Built-in USB-Serial-JTAG.** Flash + serial monitor + step-debugging over one USB cable. No external ESP-Prog / FT2232H.

**Trade-off accepted.** The S3 has no built-in DAC, so `CMD_ACC` (5V analog throttle output) now comes from an external **MCP4728** (quad 12-bit I²C DAC) on the interface PCB. 12-bit vs the classic's 8-bit is a resolution upgrade. MCP4728 shares the existing I²C bus, so no additional GPIO cost.

**Variants considered and rejected.** ESP32-S2 (has DAC but single-core, no BT), ESP32-C3 (too few GPIOs), ESP32-C6 (no DAC, Wi-Fi 6 unnecessary for a kart), ESP32-H2 (no Wi-Fi).

**Docs reframe performed today.**

- `docs/assembly/electronics/kart-medulla/index.md` — rewritten around ESP32-S3 (new pinout table, hardware decisions, Why-S3 rationale).
- `docs/assembly/electronics/kart-medulla/legacy-wiring.md` — new page preserving the classic ESP32 hand-wiring as currently deployed in the kart. **Temporary** — to be removed once the S3 PCB is deployed.
- `mkdocs.yml` — nav renamed "Kart Medulla (ESP32)" → "Kart Medulla (ESP32-S3)" with the legacy page nested under it.
- `docs/assembly/electronics/bom.yaml` — added `esp32_s3` entry (status `planned`); `esp32_wroom_32` demoted to `status: legacy` with a pointer to the legacy wiring page.
- `docs/bom/index.md` — now lists both MCUs.
- `docs/assembly/electronics/orin-setup.md` — PlatformIO flashing snippet now shows both environments (`esp32dev` for the legacy setup, `esp32-s3-devkitc-1` for when firmware migrates).

**Pointers to deeper context.**

- PCB project + `.epro` backups + full decision log: Drive folder `formula_24-25-26/dv/kart/kart-medulla/` — especially `README.md`, `history.md`, and `pinout-esp32-s3.txt` (which keeps both classic and S3 pinouts side-by-side as a reference).
- EasyEDA project: account `dv.umotorsport@gmail.com`, Personal Workspace, project ID `5b30b0a2e25c44179a5af8629b1dff0d`.

**Follow-ups.**

- Firmware (`kart-medulla` repo) needs to gain a working `esp32-s3-devkitc-1` PlatformIO/IDF configuration. `sdkconfig.esp32-s3-devkitc-1` is already present; pinout in firmware will need updating to match the S3 assignments once they're finalized during PCB layout.
- Delete `legacy-wiring.md` once the S3 PCB is manufactured, flashed, and deployed in the kart.

---

## 2026-04-23 — ESP32-S3-WROOM-1 suffix locked: N8R2 (R8 banned)

**Decision.** The exact module to order is **ESP32-S3-WROOM-1-N8R2** (8 MB flash, 2 MB quad PSRAM). Any octal-PSRAM variant (R8) is **banned** for the Kart Medulla.

**N8 vs N16 (flash).** The `N` suffix is on-module QSPI NOR flash. Flash size does not affect pinout — it all lives on the internal QSPI bus. N8 (8 MB) is plenty for this firmware (code < 1 MB, room for dual OTA slots + filesystem + growth). N16 (16 MB) is a silent upgrade path if ever needed.

**R2 vs R8 (PSRAM) — this is the critical one, and it is PHYSICAL, not firmware-configurable.**

- **R2 = 2 MB quad PSRAM.** Shares the existing QSPI flash data lines inside the module. Costs zero additional module pins. All GPIOs remain available.
- **R8 = 8 MB octal PSRAM.** The octal PSRAM die is hard-wired inside the module package to **GPIO 33–37** (the SPI0/1 extension pins). Espressif's ESP32-S3-WROOM-1 datasheet explicitly marks GPIO 33–37 as **not available** on R8 variants. Those module pads exist on the footprint but are permanently tied to PSRAM data lines inside the package.

**Why you cannot "just ignore PSRAM" on an R8 module.** Disabling PSRAM in `sdkconfig` does NOT reclaim GPIO 33–37. The PSRAM die is physically attached to the traces inside the module regardless of firmware. Driving those pads externally risks contention with whatever the PSRAM does at power-up (the ROM bootloader probes PSRAM). Treating an R8 board as if it were an R2 board is a hardware-level error, not a firmware choice.

**Rule (crystal clear).** For the Kart Medulla, only quad-PSRAM WROOM-1 variants (R2, or no PSRAM) are acceptable. R8 is rejected. This applies to the ordered module AND to any dev-board purchase — an ESP32-S3-DevKitC-1 with an N16R8 module soldered on is not a drop-in substitute for the N8R2 variant.

**GPIO 33–37 policy.** Our pinout does NOT treat GPIO 33–37 as reserved. We will try to leave them free where it is convenient, but that is a courtesy, not a commitment, and it is NOT the standard we follow. The module must make those pins available — i.e., the module must never be R8. If a future revision ever wanted to move to R8, the pinout would first have to be audited to confirm GPIO 33–37 are genuinely unused, and that audit has NOT been performed and is NOT planned.

**Alternatives on file.**

- **ESP32-S3-WROOM-1-N16R2** — valid upgrade path if firmware ever outgrows 8 MB flash. Quad PSRAM, zero GPIO cost, no PCB/pinout change required. This is the proper "fallback with headroom," replacing the previous mention of N16R8.
- **ESP32-S3-WROOM-1-N16R8** — **DISCARDED.** See above.

**Action.** Buy ESP32-S3-WROOM-1-N8R2. `bom.yaml`, `kart-medulla/index.md`, and `docs/bom/index.md` updated accordingly.

---

## 2026-04-27 — Public BOM page + steering power budget; Festo prices redacted under V2 sponsorship

**What was done.**

- New `docs/bom/full.md`: shareable consolidated BOM with two cost columns (team cost vs market cost), `Source` column (Donated / Sponsored / Purchased / Salvage / Custom), per-section tables (chassis, powertrain, steering, electronics compute & control, electronics power, sensors, EBS, wiring & misc), totals, and a tooling section sized for a "what would a new team need" view.
- New `docs/assembly/steering/power-budget.md`: back-of-envelope steering torque/power calc (μ·N·a → ~15–20 Nm static at the steering shaft, ≥100 rpm for 0.3 s lock-to-lock, ~50 W cont / ~200 W peak operating; ~2 kW stall headroom available with the current setup, rarely if ever hit). Includes a "current setup (kept)" section and an "interesting alternatives (not currently planned)" table covering Bosch F006-B20 generic wiper, Bosch WDD2 motorsport actuator, Doga 319H with Hall feedback, Doga 319.4860, generic 24V planetary gearmotor.
- `mkdocs.yml`: BOM nav split into two pages (overview + full); steering nav adds Power Budget.

**Festo / EBS pricing — what changed and why.**

The first draft of `bom/full.md` carried catalogue ballpark prices for the Festo-supplied EBS components. After re-reading the **V2 sponsorship contract** (`marketing/sponsors/festo/convenio-festo-umotorsport-2026-v2-rev-busquets-18-03-26.docx`, Busquets review 2026-03-18), the per-line Festo prices were **stripped from the public page** and replaced with `redacted` markers. V2 added:

- **NOVENA — Confidentiality.** All information accessed in the course of the agreement, 5 years post-termination, breach is "incumplimiento grave."
- **OCTAVA — IP/trademark.** Limited, revocable license to use Festo brand under their guidelines; 7-day brand removal post-termination.
- **DÉCIMA — Liability.** Festo disclaims liability; team indemnifies Festo against third-party claims.
- **UNDÉCIMA — Jurisdiction:** Barcelona (was Madrid in V1).
- **EXPONEN III** clarified the relationship as "patrocinio publicitario mediante aportaciones no dinerarias y acciones de visibilidad."
- **SEGUNDA** new bullet: supply subject to availability; no obligation of continuous/exclusive supply.

Cap on Festo's seasonal supply is **€1 500 incl. VAT per season** (Cláusula SEGUNDA-1). The team's reciprocal obligations (Cláusula TERCERA): logo on the kart, IG/LinkedIn tagging, Formula Student event invitations, sponsor listing on the team website. Term to 2026-12-31.

V2 was returned by Festo on 2026-03-18 and was being sealed by Cristina (URJC marketing). Per Jorge's chat, as of late April the signed version had not been finalised, but the redaction posture is the same either way.

**Price-research ledger kept in Drive.** Public-distributor price research (15 of 18 items priced from IAS Components, esd.equipment, Direct Pneumatics, Motion World; 3 still `?`) is preserved at `formula/formula_24-25-26/dv/kart/pneumatics/festo-public-distributor-prices-2026-04.md`. If Festo later confirms in writing that retail-equivalent estimates are publishable, the numbers can be moved straight back into the public BOM without re-research.

**Other notable BOM facts captured.**

- Orin: Silicon Highway 2023-04 invoice — net €1 821.29 + €36 shipping = **€1 857.29 transferred**, intra-EU reverse charge (0 % VAT on invoice). True project cost ~€2 247 once URJC self-accounts the 21 % reverse-charge VAT (URJC has limited input-VAT deduction as a public university). Footnote on the row explains.
- Steering: salvaged 24 V geared DC motor from a discarded massage chair, run at 12 V, through a **15 : 1** 3D-printed planetary; AS5600 angle sensor on the shaft. Bench-measured ~2 kW stall capacity; normal operation 50–200 W. Off-the-shelf wiper motors don't replace it without an equivalent reduction stage and procurement is the limiting factor for the team.
- Battery cells: 60× Molicel P42A bought from NKON for €230 (€3.83/cell), 52 in the 13S4P pack → €198. No 12 V auxiliary battery — 12 V rail comes from a buck regulator off the 48 V pack. Pack assembled by team; nickel strip + Kapton + 3D-printed PETG enclosure + fire-retardant foam liner.
- Orin storage: 500 GB M.2 NVMe pulled from a personal laptop during a 2 TB upgrade. €0 to project. Big improvement on `apt`/builds/repos; no effect on autonomy runtime FPS.

**Team-cost result.** ~€3 095 transferred to suppliers, ~€3 485 including the ~€390 reverse-charge VAT on the Orin. Page-level *market* total is redacted (the EBS row pulls the sum into non-disclosable territory); a non-Festo retail subtotal of ~€4 815 incl. VAT is shown as a partial reference.

**Open follow-ups (not closed in this session).** Sponsors page on the public site to satisfy Cláusula TERCERA-4; pneumatic schematic on the EBS page; rechecking the BOM once V2 is signed and we have the green/red on what's publishable.

---

## 2026-05-04 — drawio vs hand-crafted SVG for the wiring diagram

After thrashing through five attempts at `wiring-global` (drawio auto-routed,
hand SVG, drawio + manual waypoints, D2/ELK, drawio + electrical stencils),
the team's preference was clear: real component photos and pixel-precise
layout matter more than tool ergonomics. The fifth iteration on `wip/wiring-svg-rich`
went with hand-crafted SVG and produced a usable result on the first pass.
Notes from that experience for the next person:

**drawio strengths.** CI export is wired up (`rlespinasse/drawio-export`).
GUI editing exists for someone who prefers drag-drop. Built-in electrical
stencil library has shapes for battery, motor, switches, op-amp, relay
(actual stencil names live in `mxgraph.electrical.miscellaneous.*`,
`mxgraph.electrical.electro-mechanical.*`, etc. — extract them with
`strings /Applications/draw.io.app/Contents/Resources/app.asar | grep mxgraph.electrical`
because the names are not all guessable; the wrong path renders as a fallback
rectangle silently).

**drawio weaknesses (encountered, not theoretical).**
- Auto-routing produces spaghetti the moment edges have non-trivial geometry.
- `verticalLabelPosition=bottom` on a stencil makes the label overflow the
  cell's geometry box, so neighbors that were at the original spacing now
  collide with the label of the cell above them. The fix is either to
  re-space everything (cascading shifts because the relay block has
  internal sub-elements) or to use horizontal label position (which then
  fights with the cell width). Both routes burned an iteration.
- Photo embeds via `shape=image;image=<path>` work in CI but the path
  resolution is fiddly — relative paths to images outside the diagram's
  directory frequently render as broken-image placeholders in the CLI
  export. Data URIs work but blow up the file size.
- Edges connect by source/target cell IDs, so when you reposition a
  component the edges follow — but their waypoints don't, so the
  routing degrades silently.

**hand-crafted SVG strengths (encountered).**
- Pixel-precise placement: `<rect x= y= width= height=>` and `<polyline
  points="...">` go where you tell them. No layout engine to fight.
- `<image href="../../../emergency-braking/images/components/festo-*.png">`
  resolves correctly in any browser-based renderer (Chrome headless,
  the deployed mkdocs site, the `<object>` tag in the markdown).
  ImageMagick can't resolve those, but you don't need ImageMagick if you
  render with Chrome headless.
- Component icons drawn as inline `<path>` / `<circle>` / `<rect>` are
  free — the 13-cell battery stack, the BLDC motor rotor with U/V/W
  terminals, the SDC relay coil + NO contacts, the kill mushrooms, etc.
  Took maybe 30 minutes of careful coordinate math, no library lookup.
- White-halo edge labels (`paint-order: stroke fill; stroke: white;
  stroke-width: 4px`) just work, no fighting drawio's label background.

**hand-crafted SVG weaknesses.**
- No GUI for non-coders. The team can edit but only via text.
- Moving one component does NOT auto-reroute its edges; you have to
  update the polyline points manually. For 30+ edges this is real work.
- Verifying overlaps requires render-and-look (Chrome headless screenshot
  + Read tool); there's no equivalent of drawio's "click and drag, watch
  it snap to a clean route".

**Rendering pipeline gotcha.** ImageMagick's SVG renderer (and `qlmanage`)
do NOT load `<image>` tags via relative file paths. Render previews with:
```
/Applications/Google\ Chrome.app/Contents/MacOS/Google\ Chrome --headless \
  --disable-gpu --screenshot=/tmp/r.png --window-size=2400,1800 \
  --hide-scrollbars --force-device-scale-factor=2 \
  "file://$PWD/docs/assembly/electronics/wiring/images/wiring-global.svg"
```
The deployed mkdocs site uses real browser SVG rendering, so what you see
in Chrome locally matches what the team will see on `um-driverless.github.io`.

**Branches left for comparison (none merged to main).**
- `wip/wiring-d2-rewrite` — D2 + ELK auto-layout. Cleanest edges of any
  attempt, but every component is a generic colored rectangle.
- `wip/wiring-drawio-rich` — drawio with electrical stencils for battery,
  motor, kill switches, KEY, impact, op-amp. Acronym legend added,
  Buck/brake-bullet text corrected. Has the label-overflow / overlap
  problems that pushed us off drawio.
- `wip/wiring-svg-rich` — the hand-crafted SVG. Real Festo photos,
  schematic-style component icons, pixel-precise layout. Current
  best candidate but not yet team-reviewed.

**Bottom line.** For a documentation-grade wiring diagram with hardware-
recognizable shapes that the team isn't going to drag around in a GUI
every week, hand-crafted SVG produced a better result faster than the
drawio iterations did. drawio remains the right call for diagrams the
team WILL drag around (because the GUI saves time over coordinate math),
but those diagrams should accept the visual constraint of "labeled
rectangles with auto-routed edges" rather than fighting for stencils
and embedded photos.

---

## 2026-06-14 — BOM stays YAML-in-git, kept separate from the Notion AI Inventory (linked, not merged)

**Decision.** The published BOM stays as the `bom.yaml`-in-git system that `generate_bom_hook.py` renders into the searchable parts table. It is not folded into the team's Notion "AI Inventory" database, and it is not replaced by a public filtered view of that database.

**Context.** The Notion AI Inventory is the team's most-used tool — it tracks physical stock (tools, bolts, components) by quantity and location. It overlaps the kart, so the question came up: merge the BOM into it (a `location: kart` value), or publish a filtered Notion view as the BOM, or leave the BOM as-is.

**Why separate-but-linked is the answer.** A BOM and an inventory answer different questions and are *different sets*, not the same set filtered:

- Inventory = "what physical stock do we own, how much, where is it now" — instance/quantity-level, location-tracked.
- BOM = "what does the kart design call for" — type-level spec, by assembly, with required quantities.
- The BOM has rows with **no inventory entry**: assemblies/sub-assemblies, custom-fabricated parts (Orin adapter, Kart Medulla PCB), and design-required quantities that are a spec rather than physical stock. The inventory has rows with **no BOM line**: tools, consumables, spares. The overlap is only the COTS purchased parts.

So a "filtered inventory view" can only ever be that purchased-parts subset dressed as the whole BOM. Two pain points the user raised are the same modelling error from opposite sides: "2 bolts in the kart, the rest on a shelf — how to display" is only ugly if you model physical *units* as rows (you want one part row with quantity-by-location, not 50 rows); "two formats are hard to copy-paste on transfer" only exists if the item lives in two places.

**Publish-surface reasons to keep the docs table:** it sits inside MkDocs in-site search, it feeds `llms.txt`/`llms-full.txt` for AI ingestion, it's themed, it works offline, and it carries no dependency on a Notion page staying public. An embedded public-Notion view loses all of those.

**Link mechanism instead of merge.** Give each inventory item an optional shared part ID (`bom_id`) and each BOM part the catalog ID, so inventory↔BOM cross-reference rather than getting copy-pasted. If freshness on the overlapping purchased rows ever becomes a real problem, add a one-way Notion→`bom.yaml` pull for just those IDs — never two-way sync.

**Tipping condition that would flip this.** If the published BOM ever becomes just "the list of components we bought" — purchased COTS only, no assembly hierarchy, no custom parts, and no `llms.txt` need — then the BOM *is* the purchased-parts subset of inventory and a public filtered Notion view becomes the lower-effort, always-fresh choice.

**State found today (drives the follow-up work).**

- **Data is stale.** 6 of 8 `bom.yaml` files untouched since 2025-09 (only `electronics` 2026-05, `steering` 2025-11). Placeholder/unverified data present: `powertrain/bom.yaml` motor lists Amazon ASIN `B0C6WXYZ` (fake) as `verified: true`; several `TBD`/`pending` part numbers and round-number costs.
- **Render looks bad.** `generate_bom_hook.py` emits hand-rolled inline-styled HTML (hardcoded `background:#f5f5f5`, white-text status badges, fixed colors). It bypasses the Material theme, so there is no dark-mode support and it clashes with the rest of the site.

**Follow-up (not yet done).** (1) Audit each `bom.yaml` against the real kart and `~/dv/kart/<subsystem>/` notes — fix fake/placeholder part numbers, costs, and status flags. (2) Rework the hook's output to use Material-friendly, theme-aware markup (dark-mode safe) instead of inline styles.

**Update (same day): the styling rework (2) is done.** `docs/stylesheets/bom.css` (new) holds all table styling on Material CSS custom properties (theme-primary header, soft status/criticality badges, dark-mode ready); `generate_bom_hook.py` now emits class-based markup with no inline styles and the filter/sort JS was tidied; `mkdocs.yml` wires `extra_css`. Verified by building + screenshotting. The data audit (1) is still open.

## 2026-06-14 — QR scan resolves to the BOM (kart-docs), not the Notion inventory

**Decision.** The part-label QR system (`/scan/` → `/p/<id>/`) is for **kart parts**, and a scan resolves to that part's **BOM component / engineering docs in kart-docs**, not to the Notion AI Inventory. An inventory link stays optional/secondary on the `/p/` page.

**Why.** The motivating use case is disambiguating **versions that look physically identical** (e.g. Orin adapter v1 vs v2, ESP32-WROOM-32 *legacy* vs ESP32-S3). A QR carries a per-physical-unit opaque ID, so look-alike units get different IDs → different `/p/<id>/` pages → each links to *its* BOM component, which already encodes the revision (`status`, per-version description). The Notion inventory counts stock by *type* and can't say which revision is the one mounted, so it's the wrong primary target here.

**Permanence rule preserved.** The QR holds only the opaque ID; resolution is relative through kart-docs `/p/<id>/`. Labels never encode a Notion URL (long, org-bound → perishable sticker).

**Requirement this imposes.** For disambiguation to actually work, BOM component IDs must separate versions (`orin_adapter_v1` / `orin_adapter_v2`), not collapse to a generic `orin_adapter`.

**Obsolete versions.** Mark the superseded BOM component `status: legacy` (renders as the grey "Legacy" badge) rather than deleting it — keeps the row visible-but-retired and lets an old sticker still resolve. Delete a `/p/<id>/` page only when the physical part *and* its sticker are gone; otherwise a scan would 404. Where a unit is retired in place, point its `/p/` page at the superseding component.

---

## 2026-07-16 — tasks.md consolidated to the repo root; `.agents/tasks.md` retired

`.agents/tasks.md` was moved to `tasks.md` at the repo root with `git mv`, so the file's history follows it. `.agents/tasks.md` no longer exists in this repo and must not be recreated — the rule is one `tasks.md` per repo, at the root.

**Rationale:** tasks are the project's tasks regardless of who does them. Two files named `tasks.md` only produce duplicates and stale entries, because whichever one the current session isn't reading quietly goes out of date.

`AGENTS.md` previously didn't mention the task board at all; its "Key Files (Read Before Working)" list now names `tasks.md` first, ahead of `.agents/error-log.md` and `.agents/definition-of-done.md`.

Note: `docs/assembly/pneumatic-braking/index.md` points at `dv/tasks.md`, which is a *different* repo's board, not this one — it was already correct and was left alone. Stale `.agents/tasks.md` paths in append-only records (`history.md`, `.agents/error-log.md`) were also deliberately left as written: they were accurate on the date they were logged, and rewriting them would falsify the record.

---

## 2026-07-30 — `legacy-wiring.md` deleted: the ESP32-S3 Medulla PCB is the board in the kart

The classic-ESP32 page has been deleted, executing the plan recorded in the 2026-04-13 entry
above ("Delete `legacy-wiring.md` once the S3 PCB is manufactured, flashed, and deployed in
the kart"). Confirmed by Rubén: the ESP32-S3 interface PCB is installed and the hand-wired
classic ESP32 (ESP32-DevKitC V4, flying wires, no PCB) is out of the kart.

**Trigger.** Searching the live site for "esp32" returned "Legacy wiring (classic ESP32)" as
the *first* of 24 results, above every current page — so the top hit for the project's main
microcontroller was a retired pinout. The page carried a prominent "temporary page" warning
and was correctly nested in the nav, and that still wasn't enough: search surfaces pages
context-free, so a page that is only correct when read with its banner will be read wrong.
The lesson is that a legacy page's cost is paid at search time, not at nav time — retire it
on the day it stops being true rather than leaving it to be sorted out later.

**Removed.** `docs/assembly/electronics/kart-medulla/legacy-wiring.md` plus the five
classic-ESP32 images it was the only referent of (`esp32-devkitc-v4-pinout.png`,
`esp32-devkitc-v4-typec-header-pinout.png`, `ESP32-DevKitC-Dimensions.png`, and two that were
already orphaned: `ESP32-DOIT-DEV-KIT-v1-pinout-mischianti.png`, `ESP32-pinout-diagram.jpg`).
The nav entry under Kart Medulla is gone. The ESP32-S3 pinout on
`kart-medulla/index.md` was already complete and correct; nothing was migrated.

**Docs that still claimed the classic board was installed, now corrected.** The repo had been
inconsistent for a while — `wiring.md` and `kart-medulla/index.md` described the fabricated S3
board with its `CNx.y` terminals and physical board-rework steps, while `legacy-wiring.md`,
`bom.yaml`, and both BOM pages said the classic ESP32 was the operational setup:

- `bom.yaml` — `esp32_s3` `status: planned` → `active`; `esp32_wroom_32` description and notes
  rewritten as retired. Its `pin_assignments:` block was deleted — it held a *third*
  classic pinout that disagreed with the legacy page itself (it claimed GPIO 18/19 for the
  Orin UART and GPIO 25/26 for the motor driver) and no script read it.
- `esp32_wroom_32` keeps `status: legacy` rather than being deleted, per the 2026-06-14 QR
  convention: the row must stay resolvable so stickers on the physical modules don't 404.
- `docs/bom/index.md`, `docs/bom/full.md` — "currently hand-wired in the kart" → retired.
- `orin-setup.md` — the `esp32dev` flashing command is unchanged (it is still the image that
  gets flashed), but its comment no longer describes it as "the legacy hand-wired classic
  ESP32 currently in the kart", which is now false about the hardware.

**Stale DAC part name fixed in passing.** `docs/bom/full.md` still listed a planned "MCP4728
quad 12-bit I²C DAC", and `bom.yaml`'s `esp32_s3` entry referenced the MCP4728 twice. The
design switched to the **MCP4922** (dual 12-bit SPI) on 2026-04-17. The MCP4922 still has no
component entry of its own in `bom.yaml` — filed in `tasks.md`.

Verified with `mkdocs build --strict`: no broken links, and "Legacy wiring" no longer appears
in `site/search/search_index.json`.

---

## 2026-07-30 — Settled: the kart runs the `esp32-s3-devkitc-1` build, not `esp32dev`

The earlier entry today left an open contradiction: `firmware.md` said the board is an
ESP32-S3 while also calling the classic `esp32dev` environment "the image that actually runs
on the kart", and the `orin-setup.md` edit in that same commit repeated the claim. Both were
wrong. A classic-ESP32 image cannot run on an S3 at all — Xtensa LX6 vs LX7, and esptool
rejects the chip-ID mismatch — so this was never a question of which was more current, only
of which one was false.

**Checked directly on the kart's Orin over `orin-remote` (read-only, nothing stopped or
flashed):**

- `~/kart_medulla/.pio/build/` contains exactly one environment, `esp32-s3-devkitc-1`, with a
  `firmware.bin` from 2026-07-30 11:08. There is no `esp32dev` build directory at all.
- The ESP32 is on `/dev/ttyACM0`; no `/dev/ttyUSB*` exists on the machine. The classic board's
  CP2102 enumerated as `ttyUSB0`, so its absence is itself evidence.
- `lsusb` shows `1a86:55d3 QinHeng Electronics USB Single Serial` — the WCH CH343 on the S3
  board.

Corroborating, from session transcripts: two `pio run -e esp32-s3-devkitc-1 --target upload
--upload-port /dev/ttyACM0` runs over `ssh orin-remote` on 2026-07-26 both reported SUCCESS,
one of them immediately before a commit whose message quotes steering values "measured on the
kart". `platformio.ini` confirms `[env:esp32dev]` still has `board = esp32dev` — it was never
repointed at the S3; it is a fallback that is simply not used.

**Where the false claim came from.** `platformio.ini` still carries a comment above the S3 env
saying it "does NOT link yet", and `.agents/esp32s3-pinmap.md` still says "The S3 build does
not exist." Both were true when written and were never updated after the S3 target started
working. `firmware.md` faithfully copied them. The lesson is that a doc which cites its source
is only as fresh as that source — `firmware.md` even flagged "doc lag" in those two files
while trusting their substance.

**Fixed here:** `firmware.md` (warning block, env table, and flashing section rewritten around
the S3 target) and `orin-setup.md`. Two further errors surfaced while verifying the flashing
commands against the live machine: the repo path on the Orin is `~/kart_medulla` with an
underscore, not `~/kart-medulla`, and `pio` is **not** on the Orin's PATH (`which pio` returns
nothing) — it must be called as `~/.local/bin/pio`. The documented flash sequence would have
failed on both counts. It also now stops and restarts `kart-brain`, which holds the serial
port.

**Left open in `tasks.md`,** because they live in the `kart-medulla` repo: the three stale
statements above, and a real unresolved one — `AGENTS.md` says `km_gpio.h` uses the S3 pin map
while `.agents/esp32s3-pinmap.md` says it still holds the classic map. That one is
safety-relevant: under the classic map `PIN_STEER_PWM` is GPIO 18, which on the S3 board is
the gate of Q3, the shutdown-circuit MOSFET.

Also added the **MCP4922-E/SL** as its own `bom.yaml` component (it had none), with the
MCP4728 recorded under `rejected:`. Its unit cost is a placeholder — the chips came from
workshop stock and no price was paid.

---

## 2026-07-30 — Module standard changed: the fitted N16R8 is accepted, the "never R8" rule retired

The docs specified **ESP32-S3-WROOM-1-N8R2** and carried an explicit "DO NOT BUY" rule against
octal-PSRAM (R8) variants. The module actually on the board is an **N16R8** — an R8. So the
BOM banned the part it was describing, and the earlier edit today that flipped `esp32_s3` to
`status: active` made it worse by asserting the N8R2 was the installed part.

**Evidence the fitted module is R8:** `esptool` on the hardware reports `ESP32-S3 (QFN56)
revision v0.2` with `Embedded PSRAM 8MB (AP_3v3)` — 8 MB of PSRAM is octal, quad variants are
2 MB. Three independent statements in the firmware repo agree: `AGENTS.md` ("the kart-medulla
PCB now carries an ESP32-S3 (WROOM-1-N16R8)"), `.agents/error-log.md`, and
`.agents/esp32s3-pinmap.md` ("The fitted module is an **N16R8**").

**Decision (Rubén, 2026-07-30): accept the R8 and rewrite the rule.** The ban was written to
protect GPIO 33–37, but the pinout had already been changed to leave all five free — 33, 35,
36 and 37 are `HOLD`, `CMD_REVERSE` moved to the PCF8574 expander on 2026-05-03, and
`MOTOR_HALL_1` moved off GPIO 37 to GPIO 16. The thing the rule was protecting had already
been given up voluntarily, so the R8 costs this design nothing and the rule was the stale part.

The constraint that remains real, and is now stated that way: **GPIO 33–37 must never be
assigned.** Substituting a quad-PSRAM module (N16R2, N8R2) is a safe drop-in that *frees* those
pins; the failure case is the reverse — assigning 33–37 and then fitting an R8.

**Contradictions this cleared up, all pre-existing.** `index.md` had two adjacent admonitions
saying opposite things: a note headed "N8R2 preferred; N8R8 still works" immediately above a
danger block headed "octal-PSRAM variants (R8) are tolerated, never preferred" whose body then
said "**Do not substitute an R8 variant**" — tolerated and forbidden in the same breath. Both
are replaced by one block. `bom.yaml` separately claimed "**GPIO 33–37 are NOT reserved by our
pinout** ... the pinout may and does use GPIO 33–37 when needed", which the pin table on
`index.md` had contradicted since at least 2026-05-08 by marking all five `HOLD`. And
`index.md` still described `CMD_REVERSE` as living on GPIO 36 flagged `SPARE/CMD_REVERSE`,
two months after it moved to the PCF8574.

Also corrected while sweeping: `docs/bom/full.md` still listed the medulla PCB as "next
revision, blank" with its terminal blocks and level shifters as "Planned", though the board is
fabricated, populated, and running the kart; and `wiring.md` linked to the medulla page as
"Kart Medulla (ESP32)".

**Naming note for anyone reading old text:** "N8R8" appears in a few places in the pre-2026-07-30
docs where "N16R8" was meant. N8R8 is a real Espressif part (8 MB flash, 8 MB octal PSRAM), just
not the one on this board.

---

## 2026-07-30 — Pin table diffed against dv-hardware; U12 does not exist, the part is Q4

Following the module-suffix fix, the ESP32-S3 pin table was compared row-by-row against its
declared source of truth, `dv-hardware/projects/kart-medulla/docs/pinout-esp32-s3.md`. The
kart-docs table claimed to mirror it "as of 2026-05-08"; that file has since been edited twice
(2026-07-10 bench bring-up, 2026-07-18), so the claim was ~2.5 months stale.

**All 44 rows agree except two, and on those two kart-docs is the more current side.**
dv-hardware still lists GPIO 1 as `PRESSURE_3` and GPIO 3 as `BUZZER` in its `Signal` column
even though its own notes describe both reassignments. So the blanket "if the two disagree,
dv-hardware wins" rule would have *undone* the steering-angle-PWM and compressor-PWM
repurposings. The rule is now scoped: dv-hardware wins everywhere except those two rows, and
the underlying fix is filed in `tasks.md` as an upstream job.

**Corrections pulled down from the 2026-07-10 bench session:**

- **GPIO 3 is not a strap pin on this chip.** The old note said "Strap pin (JTAG src select),
  idle-high at boot is acceptable". Both halves were measured wrong: the `STRAP_JTAG_SEL` eFuse
  is unburned so GPIO 3 is never sampled at reset, and `IO_MUX_GPIO3 = 0x0a02` shows no
  internal pull, so it floats and an external pulldown wins at boot. That is precisely why it
  is safe driving the compressor MOSFET gate.
- **GPIO 35–37 are `BLOCKED`, not `HOLD`.** With an N16R8 fitted they are not reclaimable at
  all, so the status legend now separates "kept free by choice" from "physically impossible".

**U12 does not exist.** The docs described the REVERSE-wire driver as "U12, a PC357N1J000F
optocoupler, swapping to a BSS123 in the next schematic edit, board not yet manufactured, swap
is free". Every clause was wrong: the part is **Q4**, a BSS123, already fitted on a
manufactured and bench-tested board. The netlist's reference designators are
`U1, U02, U5, U13, U14, U19, U23, U24, U25` — no U12 anywhere in schematic, PCB, netlist or
BOM. The optocoupler was never placed on a sheet; it survives only as an unused library entry
in the EasyEDA source, and even the 2026-05-03 export already has the BSS123 placed as Q4.

**One conflict left open rather than guessed at.** kart-docs puts the reverse-command wire on
terminal **CN4.3**; the dv-hardware netlist puts `/REVERSE_WIRE` on **CN8 pin 1**, which
kart-docs assigns to `SDC_IN_LOW_SIDE`. Mixing up a reverse command with the shutdown-circuit
terminal is not a harmless error, and nothing on hand settles it — CN6–CN10 are already flagged
as possibly physically reversed. Both `index.md` and `wiring.yaml` now carry an explicit
"unverified" marker at that terminal, and it is filed in `tasks.md` for a check against the
board.

Verified after the edits: `check_wiring.py` still reports 115/115 connectable pins wired, and
`mkdocs build --strict` is clean.

---

## 2026-07-30 — CN4.3/CN8.1 settled: kart-docs was right, the dv-hardware netlist's CN numbers are not the silkscreen's

Confirmed by Rubén: on the board, **CN4.3 carries REVERSE and CN8.1 is `SDC_IN_LOW_SIDE`** —
exactly what `wiring.yaml` and `kart-medulla/index.md` already said. The "unverified" markers
added to both files earlier today have been removed.

The discrepancy that prompted them is real but lives upstream, and it is worse than a swapped
pair. `dv-hardware/projects/kart-medulla/output/netlist.net` (exported 2026-05-07) puts
`/REVERSE_WIRE` on **CN8 pin 1** *and* `/SDC_IN_LOW_SIDE` on **CN5**. Two nets, two different
mismatches — so the netlist's `CN` reference designators are simply not the silkscreen `CN`
numbers, rather than being off by a consistent permutation. The KiCad project is a ConvertEDA
import of the EasyEDA original, which is the likeliest point at which connector designators
were reassigned.

The consequence is worth stating plainly, because it is the kind of thing that gets someone
hurt: anyone wiring the kart from that netlist would land the **reverse command on the
shutdown-circuit terminal**. Filed in `tasks.md` — the netlist stays useful for nets and part
designators (it is how `Q4`/BSS123 was confirmed), but it is not authoritative for terminal
numbers until the designators are reconciled.

**Method note.** The mismatch surfaced only because the pin table was diffed against its
declared source of truth instead of being trusted, and it was resolved only by asking the one
person who could see the board. Neither half would have worked alone: the diff found the
conflict but had no way to say which side was right, and the netlist looked authoritative
precisely because it is machine-generated. Machine-generated does not mean correct about
physical labels — it means faithful to whatever the schematic's designators say, which is a
different claim.

---

## 2026-07-30 — `km_gpio.h` settled: both pin maps live behind a compile-time switch

The last open safety question is closed, and the alarming version of it was wrong.
`components/km_gpio/km_gpio.h` does not "hold the classic map" *or* "hold the S3 map" — it
holds **both**, selected by `#if defined(CONFIG_IDF_TARGET_ESP32S3)` with the classic map in
the `#else` branch. Building the `esp32-s3-devkitc-1` environment takes the S3 branch:

- `PIN_STEER_PWM` = GPIO 40
- `PIN_STEER_DIR` = GPIO 17
- `PIN_SDC_NOT_EMERGENCY` = GPIO 18
- `PIN_STEER_PWM_IN` = GPIO 1, commented `CN5.2 — MT6701 OUT, ~994 Hz PWM angle frame`

which matches the kart-docs pin table on every one of those pins, including the GPIO 1
repurposing that dv-hardware's own table has not caught up on.

So `AGENTS.md` was right and `.agents/esp32s3-pinmap.md` is stale. The hazard raised earlier
today — "under the classic map `PIN_STEER_PWM` is GPIO 18, which is Q3's gate" — is real about
the `#else` branch and irrelevant in practice, because that branch is not compiled for this
board. Worth recording as a false alarm rather than quietly dropping: the reasoning was sound
but rested on treating two docs' disagreement as evidence about the code, when the code was
readable the whole time and answered it in one grep.

Remaining stale statements in the firmware repo are consolidated into a single `tasks.md`
entry, now including `km_gpio.h:108`, whose `#else` branch is still labelled "(current build)".

---

## 2026-07-30 — Audited the docs nobody had opened: software, mechanical, rules, top-level

The electronics sweep earlier today only covered `docs/assembly/electronics/**` and
`docs/bom/**`. Three parallel audits covered the rest, and their claims were then checked
against two authorities rather than taken on trust: the `kart-brain` ROS 2 source, and the live
Orin.

**Two facts settled by looking at the running machine.** `/dev/serial/by-id/` on the Orin holds
exactly one entry, `usb-1a86_USB_Single_Serial_5C37207028-if00 → ttyACM0`, which matches the
`serial_port` default in `kb_coms_micro.cpp:6` — so the docs' Silicon Labs CP2102 path was
stale on both counts (wrong vendor, and the real default is a `by-id` path rather than a bare
device node). And `ss -tlnp` shows the dashboard process listening on **port 80**, confirming
`dashboard.md` and refuting the three pages that said 8080.

**The most consequential fix was a latency figure that inverted a conclusion.**
`performance.md` documented the ESP32 PID loop at 10 Hz / ~100 ms and drew the reasonable
conclusion that the microcontroller was the pipeline's largest tail after perception. The
firmware's actual control task targets 500 Hz (2 ms). `firmware.md` had already flagged 10 Hz
as a superseded number months ago; `performance.md` was the surviving copy. Fixing the number
also required rewriting the surrounding prose, the pipeline budget diagram, and a measurement
checklist item that asked whether "the 10 Hz PID cycle" was stable — a stale number does not
sit in one cell, it grows conclusions around itself.

**Corrections applied.** `/dev/ttyUSB0` → `/dev/ttyACM0`; CP2102 → the real WCH by-id path;
port 8080 → 80 in three places; `cmd_vel_bridge` documented as subscribing `/kart/cmd_vel`
when the source says `/kart/cmd_vel_muxed` (the wrong version implied the state-machine safety
mux was bypassed); `zed2i` → `zed2`; YOLOv11s at 640 px → YOLOv11n at 320; `/esp32/health` →
the real `/esp32/health/flags` + `/esp32/health/data`; `/esp32/throttle` marked as
simulator-only, since on hardware `kb_coms_micro` publishes `/esp32/acceleration` and that
dashboard dial stays blank; `ros2 launch kb_dashboard dashboard.launch.py` → `kart_bringup`
(both packages have a file by that name, and they are not equivalent); and
`state_machine.md`'s claim that the gamepad publishes `/kart/cmd_vel_manual` — it publishes
`/kart/cmd_vel`, the *autonomous* input, which is worth knowing before trusting the mux.

Outside software: `faq.md` argued the Orin's 40-pin header could replace the ESP32 because it
has "2 hardware PWM channels (steering servo + motor ESC)". There is no ESC and throttle is not
PWM — it is an analog DAC output — so the trade-off was mis-scoped, not merely mislabelled.
`index.md` was dated `2025-06-18`, ten months before the kart existed, and both it and
`about.md` still said steering actuation was "ordered" three weeks after the kart drove itself.
`assembly/index.md` described the MCU as "ESP32, UART 115200" and throttle as "0–3.3 V (66% max
until 5V DAC available)" — a limitation the fitted MCP4922 removed. The CAN diagram on
`steering/index.md` and the CAN transceiver line on `computer.md` both contradicted "no CAN
anywhere on the kart"; the transceiver is real but unused, so that line now says so.
`as_state_machine.md` described the dashboard stop button as equivalent to ASMS-off when it
returns to `AS_READY` and stays armed.

Also: `docs/rules/` was reachable only by an inline link and is now in the nav; the orphaned
`assembly/electronics/microcontroller/` directory (a Blue Pill page and two pinout images from
before the medulla existed, referenced by nothing) was deleted; and the build-journey's
"every Wednesday" claim was softened, since 5 of 13 posts landed on a Wednesday.

**Left open in `tasks.md`, four items that need a person or a multimeter:** what actually powers
the Cytron H-bridge (two pages say the 12 V rail, `steering/index.md` says the 48 V pack and
specs stall at 47 V × 43 A); rewriting the camera page's YOLOv5 export walkthrough for v11;
whether the kart is presented as a competition entry (`index.md` says it will not compete,
`as_state_machine.md` calls it an APC entry and tracks rule compliance); and reconciling three
different mission lists — during which the audit turned up a live bug worth repeating here:
`throttle_test` is gated as an autonomous mission but is missing from `protocol.py`'s
`MISSIONS` map, so `MISSIONS.get(..., 0)` sends it to the ESP32 as **manual**.

---

## 2026-07-30 — The Cytron runs off the 48 V pack; the 12 V claim was wrong in three files

Settled by Rubén: the steering H-bridge is fed from the **48 V traction pack**, not the 12 V
rail. So `steering/index.md` — the page flagged as the outlier when the audit found this — was
the correct one, and the two pages that agreed with each other were both wrong. Worth
remembering: two sources agreeing is not evidence, when one was written by copying the other.

Corrected `kart-medulla/index.md` (the 2026-05-01 decision entry) and
`electronics/power/battery.md` (which listed the H-bridge among the 12 V rail's loads). In
`wiring/wiring.yaml` the Cytron's supply pin moved from the `12V` net to `PACK48` and was
renamed `v12` → `vin` — the old pin name encoded the wrong answer, so leaving it would have
re-seeded the error — and `STEER_M+` / `STEER_M-` are re-labelled 48 V. `check_wiring.py` still
reports 115/115 pins wired.

The Cytron MD25HV takes 7–58 V, so the pack is within spec, which is why nothing downstream
needs to change. The "powered permanently, not switched through the manual/autonomous mode
switch" half of the original decision is unaffected: that was about inrush current browning out
the Orin on every switch into autonomous, which is a question of *when* it is connected, not of
*which rail*. Only the rail was wrong.

---

## 2026-07-31 — Part IDs are per-design, not per-physical-unit (amends 2026-06-14)

**Decision.** A part ID (`part_id`, the 16-digit number in the QR) identifies a **design revision**,
not an individual physical object. Every board built to the same revision carries the same sticker
and resolves to the same `/p/<id>/` page. Ruben's call, 2026-07-31.

**What this changes.** The 2026-06-14 entry above ("QR scan resolves to the BOM") wrote "a QR carries
a per-physical-unit opaque ID". That wording is superseded. Its *reasoning* is untouched and in fact
argues for per-design: the motivating case is telling apart versions that look physically identical
(Orin adapter v1 vs v2, ESP32-WROOM-32 vs ESP32-S3), and a per-design ID separates those completely.
Per-unit IDs would only add distinguishing two boards of the same revision from each other, which
nothing in the project needs, at the cost of a unique sticker and a unique page per object built.

Everything else in that entry stands: the QR holds only the opaque ID, resolution is relative through
`/p/<id>/`, superseded revisions get `status: legacy` rather than deletion so old stickers still
resolve, and a `/p/` page is deleted only when the part and its stickers are gone.

**Vocabulary, so the two levels have real names.** The design-level number is a **part number** (PN;
**MPN** when it is the manufacturer's own, **GTIN** in the GS1 barcode world). A per-object number is a
**serial number** (SN; **UII** under MIL-STD-130's IUID scheme, **SGTIN** in GS1/EPC). This project has
the first and not the second. If per-object tracking is ever needed, add a `serial` field alongside
`part_id` rather than redefining `part_id` — PN plus SN on one label is the standard form, and it
extends the scheme without invalidating a single printed sticker.

**Consequence for revisions.** Each revision needs its own part ID and its own page, since the ID *is*
the revision. Created the same day: `Kart Medulla PCB v2` = `1604 0948 4608 5574`
(`docs/p/1604094846085574.md`).

**Addendum (same day) — the names we use.** The standard names read backwards to us ("part number"
sounds like it names the object; "serial" sounds like it must count up, and modern ones often do not),
so the project uses plain names, with the standard ones kept as the translation for suppliers:

| Level | Our name | Standard name |
|---|---|---|
| The design revision — every unit built to it shares this | **design ID** | **PN**, part number (**MPN** when it is the manufacturer's own) |
| One individual physical object | **unit ID** | **SN**, serial number |

The 16-digit number in the QR is a design ID. There is no unit ID in the system, and adding one would
mean a second field, not a redefinition of the first. Use PN/MPN when talking to suppliers — that is
the term they answer to. The `part_id` field name is unchanged for now; renaming it to `design_id`
would touch `scripts/new_part.py`, `docs/scan.md`, `docs/p/index.md` and the frontmatter of each
existing part page.

**Not UII.** MIL-STD-130's unique item identifier was considered as a name for the unit ID and
rejected: a UII is not a bare number but a concatenation of issuing agency code + enterprise
identifier (CAGE/DUNS/DoDAAC) + serial (Construct 1), or the same with the part number inserted and
the serial only unique within it (Construct 2). It presumes a registered enterprise, and the standard
also specifies the mark as Data Matrix ECC 200 with a defined data syntax rather than a QR carrying
bare digits. The serial component itself may be random — nothing in the standard requires counting up
— but that does not make a random number a UII. SN stays the standard equivalent of unit ID.

## 2026-08-08 — CN1–CN10 pinout published, and cross-repo links pinned to commits

The medulla connector table was never missing, just invisible from here: it lives in dv-hardware as
`projects/kart-medulla/docs/pinout-cn-connectors.md`, next to the KiCad schematic that defines it,
and this repo only linked at it in prose. `scripts/sync_pinout.py` now copies it verbatim into
`docs/assembly/electronics/kart-medulla/pinout.md` under a provenance banner. Still one authored
table, so the drift that got the old hand-maintained tables deleted cannot return.

The copy is committed rather than rendered by a mkdocs hook the way the wiring and BOM tables are,
because GitHub Actions checks out kart-docs alone and cannot reach dv-hardware at build time.
`--check` reports staleness wherever the source is visible and exits 0 where it is not.

**Cross-repo links are pinned to a commit, never `main`** (Ruben's rule, this session): a `main`
link silently changes meaning as the other repo moves, so a reader comparing the copy against
"the source" would be reading a different document than the one that produced it. The banner
carries a permalink to the exact revision plus its date; syncing from a dirty dv-hardware working
tree is refused, because such a copy would correspond to no commit. `--allow-dirty` overrides.
`pinout-esp32-s3.md` and `esp32-s3-pin-capabilities.md` links in the medulla page are pinned too;
dv-hardware's `projects/kart-medulla/README.md` is deliberately left on `main`, because it is a
living rework list that is meant to be read as current state.

Three things found while doing it:

- **Every `dv-hardware` link in this repo pointed at `github.com/rubenayla/dv-hardware`, which
  404s.** The remote is `UM-Driverless/dv-hardware`. All of them were dead; all are fixed.
- Two stale pointers on the medulla page: it told readers to filter the wire list's `From`/`To`
  columns (the column is `Connected pins`, and pins read `medulla.CN1.2`), and claimed the
  "ESP32-S3 Pin Assignment" section above held a table with a `Silkscreen` column — that section
  explicitly carries no table.
- kart-docs and kart-medulla disagreed on the CN5.2 rework. This repo said remove R10 only; the
  firmware repo said R9+R10. Ruben confirmed this repo was right, and kart-medulla was corrected
  (`078e34e` there). kart-medulla also still called the steering sensor an AS5600.

kart-medulla reads dv-hardware directly rather than going through kart-docs: it is a peer of the
hardware repo, and a hop through the docs site could only ever be staler than what it reads today.

## 2026-08-08 — the mode switch is DPDT and the diagram only showed one of its poles

Rubén, correcting a wrong assumption of mine: the manual/autonomous selector is "a normal DPDT
switch in the panel of the kart". Both poles matter and only one was documented.

- **Pole 1 — throttle source.** Already in `wiring.yaml`: pedal or medulla `CMD_ACC_DAC` to the ESC.
- **Pole 2 — steering motor.** Was missing entirely. It breaks the cable from the Cytron H-bridge
  to the steering motor, so in manual the motor is physically disconnected from its driver. The
  netlist had `STEER_M+` running straight from `cytron.mplus` to `steer_motor.mplus`; it is now
  split into `STEER_M+_SW` (Cytron → switch) and `STEER_M+` (switch → motor).

**The Cytron's supply is not what the switch gates**, which is the part that had been confusing.
It sits permanently on PACK48; gating it was tried and reverted because the inrush at every
switch-to-autonomous browned out the Orin. Only the motor cable is broken.

**Which conductor pole 2 actually breaks is not verified** — M+ is what the netlist now assumes.
Buzz it before trusting the row; if it is M− or both, move it.

**Why the design is a switch and not electronics.** Manual mode works with the entire electronics
side unpowered, because metal contacts hold their position with no supply and no firmware. This
came up because `dv-hardware` had a MAX4660 analog mux on the medulla doing the same throttle
selection, believed to pass the pedal through when unpowered. It does not — a CMOS switch is open
at V+ = 0 (see the `dv-hardware` history entry of the same date for the datasheet evidence). The
panel switch was doing the real work all along, so the mux is redundant and is being deleted in
medulla-v2 rather than fixed.

**Still missing: the medulla cannot read the mode.** Nothing routes the switch position back to
it. Planned fix is a third pole shorting a sense wire to ground in autonomous, against a pull-up
on the medulla — read-only, so firmware can observe the mode but never cause it. Not built; the
medulla pin is part of the v2 allocation being decided in `dv-hardware`.

**Found and not fixed:** the SVG still shows the Cytron on 12 V, contradicting the 2026-07-30
decision that it runs off the 48 V pack. Filed in `tasks.md` — it needs a reroute, not a
relabel, so it was left alone rather than half-corrected.

### Same day — both open questions closed by Rubén

1. **"motor + is the one switched."** The mode switch's second pole breaks **M+**; M− runs
   straight through. The `STEER_M+_SW` / `STEER_M+` split in `wiring.yaml` was already modelled
   that way and is now stated as confirmed rather than assumed.
2. **"cytron is powered directly from the battery. confirmed."** So the SVG's `12 V → Cytron`
   wire was wrong in topology, not just in its label. Rerouted to branch off the battery run at
   (900, 1410) and climb the x = 1610 corridor to the Cytron, drawn in bold stroke because the
   legend already defines bold red as 48 V. First attempt routed it up x = 1900 and it crossed
   straight through the acronym legend box (1620–1960, y 80–350) and Kill 2 at (1700, 910) —
   caught by rendering the SVG to PNG and looking at it, which is the only way these collisions
   show up in a hand-written SVG. x = 1610 threads between the perception zone (ends 1600) and
   the legend (starts 1620).

Also corrected while there: the Cytron box said `25 A · 12 V`, now `25 A · 7–58 V in` (its real
input range, so the number stops implying a supply choice), and the steering motor box said
`DC 12 V`, now `fed from the 48 V bridge`. The motor's own voltage rating is still not recorded
anywhere — worth measuring or finding, but it is no longer being asserted wrongly.

### Same day — the steering motor is a 24 V part run at 48 V, on purpose

Closing the "motor voltage not recorded" note I left earlier that day: it **was** already recorded
— `docs/assembly/steering/index.md` has said "24 V geared DC motor (salvaged), driven from the
battery" all along. What was missing was the reason that is acceptable, which is the part a reader
would otherwise file as a bug.

Rubén, 2026-08-08: the motor is rated 24 V and runs off the ~48 V pack deliberately. It is never
worked hard continuously, it is well cooled, and firmware caps PWM at 50 % duty, so the average
voltage across it is about its rating. He is explicit that even removing the 50 % cap would not
damage it, given the duty cycle — so the cap is margin rather than the thing keeping the motor
alive.

Recorded in three places so it survives: a "Why a 24 V motor runs off the 48 V pack" section on the
steering page, the `steer_motor` description in `wiring.yaml`, and the motor box in the global SVG
(now "24 V motor on 48 V / intentional — PWM capped 50%") instead of the vague "fed from the 48 V
bridge" I had put there hours earlier.

**The firmware consequence worth carrying forward:** the 50 % PWM cap exists for a hardware reason.
Anyone treating it as an arbitrary tuning number and raising it should at least know why it is
there. Noted on the steering page next to the reasoning.

What would actually change this judgement is duty cycle, not voltage — sustained holding against
load rather than move-and-release.

## 2026-08-08 — Steering gears broken during a reflash; the board has no hardware default for steering

The steering swung to full lock while the ESP32-S3 was being reflashed with the kart in autonomous,
and broke teeth off the steering gears. Full diagnosis and the firmware response are in the
kart-medulla repo's `history.md`, same date; the requirement that came out of it is dv-hardware
`projects/kart-medulla/requirements.md` REQ-08.

What matters for these docs: the line in
`docs/assembly/electronics/kart-medulla/index.md` that reads *"Steering is NOT muxed — the ESP32
always drives the Cytron H-bridge directly; in manual mode firmware sets PWM = 0"* turned out to be
the whole story of the failure. It was written as a description of the mux's scope. It is also a
statement that steering has no safe state when firmware is not running, which is every reset and so
every flash — and nothing in these docs said that out loud.

The contrast is on the same page: `SELECT_THROTTLE` gets R32's 10 kΩ pulldown so the driver's pedal
takes over whenever the ESP32 is unbooted or crashed, and the compressor MOSFET gate has a 100 kΩ
pulldown holding it off through boot. Two outputs designed to fail safe, one that was not, and the
asymmetry was documented without ever being named as one.

A task is filed in this repo's `tasks.md` for the pulldown, including the meter test that separates
the two candidate causes, because the cause is not settled — Ruben's reading is that the swing
happened during the flash itself rather than just after the reboot.

## 2026-08-14 — Removed the "other repos are stale" banners, and a structure pass

Ruben, on the S3-build warning at the top of
`docs/assembly/electronics/kart-medulla/firmware.md`: noting that the repos are wrong instead of
fixing them is a botched idea. He is right, and the banner had already rotted — two of the three
statements it warned about had been corrected in `kart-medulla` on 2026-08-10, so the warning was
itself the stale doc by the time it was read. Fixed the sources (written up in
`kart-medulla/history.md`, same date) and deleted all three banners here: the S3-build one, the
"older task-rate figures elsewhere are superseded" one, and the "PID gains differ across sources"
one.

Corrections that came out of doing it, all checked against `main/main.c` and `kart-brain`:

- The PID callout's own numbers were stale. It said Kp 1.50 / Kd 0.02 citing `main.c:277-279`; the
  code has `PID_DEFAULT_KP` 1.00 and `PID_DEFAULT_KD` 0.05. A banner warning that other files drift
  had drifted. The page now names the constants and their file instead of citing line numbers,
  which move.
- The task table said `control`'s real rate was "capped by the blocking I2C AS5600 read, so it runs
  below 500 Hz". It is not — the MT6701 is read by MCPWM capture, nothing in the loop blocks, and
  500 Hz is measured via `control_iters`. The cap is UART bandwidth.
- The steering pipeline said the AS5600 is read over I2C. Sensor changed 2026-07-12.
- The comms-loss section said the firmware "does not drive [the SDC] yet". It has since 2026-07-26;
  what is missing is the wire from Q3's gate. Split into its own "Shutdown circuit (SDC)" section
  with the whitelist conditions spelled out, so the distinction between "logic runs" and "nothing
  happens physically" is visible rather than buried in a negative.
- Added a danger callout about de-powering the steering before a flash. The steering pins float
  through the bootloader window and this broke gear teeth on 2026-08-08; it was recorded in
  `kart-medulla/AGENTS.md` and in this repo's `tasks.md`, but nowhere on the published site, which
  is what a human at the kart actually reads.
- `kart-medulla/index.md` claimed "Native USB-OTG — the Orin link becomes a direct USB cable,
  dropping the USB-UART bridge IC". That is the S3's capability, not the kart's wiring: the link
  runs over UART0 through the DevKitC's CH343 bridge at 115200. Both the "Why ESP32-S3" bullet and
  the "Orin link" hardware-decision line now say what is actually connected.
- `assembly/sensors/camera.md` carried a "the YOLOv5 sections below are out of date" banner over a
  walkthrough for the ZED wrapper's built-in ONNX detection. Both halves needed work: the version
  (YOLOv11n now) and the framing. There are genuinely two modes — our own `yolo_detector` node,
  which is the default, and the ZED SDK's built-in detection, which `perception_zed_od.launch.py`
  exists for. The ONNX steps belong to the second and are now labelled as such, so nothing had to
  be deleted.
- `software/ros2/packages.md`'s `yolo_detector` parameter table was checked against the node while
  there: `conf_threshold` 0.25 -> 0.10, `imgsz` 640 -> 320, `device` default is auto-detect not
  `cpu`, and `crop_top` was missing entirely.
- `orin-setup.md` listed YOLOv5 in the JetPack-compatibility sentence.

Structure, since the same request asked whether the organisation makes sense:

- `docs/hydraulics/` sat at the top level while the nav filed it under Assembly, so the two braking
  systems lived in different places. Moved to `docs/assembly/hydraulics/` and rewritten — it opened
  with a bare bullet and no statement of what the hydraulics are for. It now says the pneumatics
  actuate these brakes, which is the fact that makes the two pages make sense together. Flagged
  that the recorded Sensata part code and the Mouser link on the same page are different variants;
  filed as a task rather than guessed at.
- `diego-design.md` renamed to `design-history.md` (named for the job, not the author) and added to
  the nav — it was linked from the pneumatics page but invisible in the sidebar, and was the only
  page mkdocs reported as missing from the nav. The build is now warning-free.
- Deleted `TODO.md`: a second, Spanish, task list at the repo root next to `tasks.md`, holding a
  plan for a Blue Pill v2 board with an AliExpress I2C DAC module. Superseded by the medulla PCB
  and its MCP4922. The CAN part link it also held moved to `stuff.md`, which is the declared home
  for links with no better place.
- `tasks.md` had a `## Done` section on the board while its own header said closed items live in
  `tasks/done-archive.md`, a file that did not exist. Created it and moved the eight closed entries
  across, plus the three this session closed.
- `assembly/index.md`'s trailing "Notes" was two bullets and a literal `...`. Kept the facts, said
  what the section is for, and turned the unknown bearing-spacer dimensions into an explicit
  measure-this rather than a `?` that reads as a typo.
- `electronics/computer.md` was three H1s deep with "Power consumption:" left blank and "Specs:
  TODO". Filled the specs from `orin-setup.md` (they were already recorded there), fixed the
  heading levels, and pointed the software half at the setup page instead of half-duplicating it.

## 2026-08-14 (later) — The AS5600 → MT6701 swap was never written into kart-docs

Ruben asked where the "why we dropped the AS5600" reasoning should live, and whether `faq.md` was
the place. It isn't: the FAQ holds whole-project questions (why pneumatic braking, why electric,
why an ESP32 at all) that someone asks before they know where anything lives. A decision about one
component belongs on that component's page, or the page has to link out for its own most important
fact. Rough test used: if the answer would change when you swap the part out, it goes on the part's
page.

Then his correction, which was the right one and I should have reached myself: obsolete material
must not be laid out like current material. Collapsed `??? info` blocks, not normal headings.
House style already had this — `powertrain/fasteners.md`, `steering/h-bridge.md`.

`assembly/steering/sensor/index.md` was written from before the swap: "Current sensor: AS5600 over
I2C (validated)… it is the validated, in-use sensor", with the MT6701 as "plan of record" that
"**will be** mounted", hardware "expected to arrive around 2026-07-22". The AS5600 was retired
2026-07-12 and the MT6701 has been reading on the kart since the end of July. Rewritten: MT6701
current, the two reasons for the change promoted to their own section, everything AS5600 collapsed
under a `## History` heading.

**The reason for the swap was only ever in `kart-medulla/history.md`,** which is the actual gap
behind his question. Now stated on the page: the AS5600 reconstructs the angle from how the *axial*
field varies across a 1 mm circle on the die, and the kart's shaft magnet is two large magnets stuck
sideways, which gives a field that is strong but nearly uniform over that span — nothing to measure,
so it reports no-magnet and gates its own output even touching the magnet. The MT6701 senses the
*direction* of the in-plane field at a point, which a big magnet defines cleanly. Sensing principle,
not resolution or price. The cable-length reason (medulla at the rear, ~1.2 m, I2C glitch hangs the
shared PCF8574 bus) is real but second — it is why PWM rather than I2C, not why this chip.

Kept two honesty caveats from the source notes rather than letting the page read as a win: the
MT6701 wants essentially the same small magnet and tight gap as the AS5600 (it tolerates our
uniform-field problem, not sloppy mounting), and past its 0.3 mm off-axis figure it degrades
smoothly rather than failing — a different failure class from the AS5600's detection failure.

**Five more pages still called the AS5600 current**, found by grepping rather than assumed:

- `wiring.md` — "Current (validated): an AS5600 … it works today", with the MT6701 as "Planned".
- `steering/index.md` — three places: the architecture paragraph, the signal-chain ASCII diagram,
  and step 1 of "Main process".
- `steering/motor-options.md` — feedback source, and a Doga-motor note about dropping "the AS5600
  and one I2C bus".
- `steering/h-bridge.md` — a VESC alternative saying to keep the sensor on I2C.
- `software/ros2/performance.md` — the same wrong claim already fixed on the firmware page earlier
  today: that the loop runs below 500 Hz because the I2C read blocks. It runs at 500 Hz, measured
  via `control_iters`; the cap is UART bandwidth. Also an open measurement item built on the same
  false premise, rewritten to ask about UART-write jitter instead.
- `faq.md` — one line listing I2C/AS5600 among peripherals the Orin's header could absorb. Replaced
  with the real obstacle: the angle now arrives as a ~994 Hz PWM whose duty carries the value, and
  one count is 244 ns of edge timing — a hardware-capture job, which strengthens rather than
  weakens the answer that the ESP32 earns its place.
- `software/dashboard.md` — the Magnet+AGC and I2C cards were documented as live readouts. They are
  permanently blank on this board, and kart-brain's own `index.html` already said so ("never
  populated on this board… would peg the chip to a permanent false alarm"). Marked as such.

Left alone deliberately: `build-journey/index.md` (dated posts — the June entry was true when
written, and the 2026-07-30 post already explains the swap), `pinout.md` (generated from
dv-hardware by `sync_pinout.py`, must be fixed upstream), and `packages.md`'s `ESP_DIAG_STEERING`
row (checked against `km_coms.h` — the frame really is AS5600 diagnostic registers, still valid on
the classic build).

Filed rather than guessed: `steering/fasteners.md` and `fasteners/bom.yaml` give screws and an
assembly order for mounting an AS5600 board to a bracket, and the MT6701 breakout is a different
board — needs someone at the kart. And the steering BOM lists the AS5600 with no MT6701 at all.

## 2026-08-14 (later still) — Three "ask Ruben" items were lookups, and two of my claims were wrong

Ruben on the three questions I ended the previous handoff with: *"super imprecise and unneeded
question. 3d printed holder, pressure sensor should be from the festo sponsorship notes, in
inventory also, i dont know what a bearing-spacer is, but we have the whole cad in fusion 360."*

He is right, and the shared instructions already say so — his repos are more accurate than his
recall, so asking him to enumerate facts on disk spends his turn on a lookup. All three were
answerable from `~/dv/`.

Worse, going to look turned up two things I had asserted wrongly on the sensor page, both because I
built it from `kart-medulla/history.md` and never opened `~/dv/kart/steering/history.md`:

1. **The sensor is FRONT-mounted, and always was.** Ruben, 2026-07-31: *"front! always was front.
   already done. with great 3d printed adjustable mount"*. I had written the cable-length argument —
   medulla moving to the rear, ~1.2 m, I2C unreliable over that run — as a reason for choosing PWM.
   That was the 2026-07-14 plan, which the same entry records as never having happened and not
   pending. The page now says so explicitly, because the claim is still sitting in `wiring.md`'s
   history and will otherwise get copied forward again.
2. **The two repos disagree about why the AS5600 was dropped**, which is the thing he originally
   asked me to document. `kart-medulla/history.md` has the magnet-physics story: axial field must
   vary across a 1 mm circle, the kart's two big sideways magnets give a uniform field, magnet-detect
   read zero with the chip touching the magnet. `~/dv/kart/steering/history.md` (2026-07-31) says
   *"magnet tolerance turned out not to be a real risk on this kart — the AS5600 already read the
   installed magnets fine, and the MT6701 confirms it."* The bench magnet was handheld and the kart's
   is mounted, which plausibly explains both, but nobody has reconciled them. I had written the
   magnet story as settled fact with a mechanism. Now presented as an open disagreement with both
   sides quoted, and filed.

The other two lookups:

- **The Sensata hydraulic pressure sensor is not fitted.** `~/dv/kart/pneumatics/README.md`:
  *"Hydraulic pressure sensor (Sensata PTE/700-33) - not used in this system"*, and the 2026-04 Festo
  price sheet lists it as *"Not Festo; on hand, currently unused"*. The kart-docs hydraulics page
  presented it as "our pressure sensor" with a spec table, i.e. as installed hardware. Rewritten as
  bought-but-not-fitted, with a pointer that the *pneumatic* sensors (Festo SDE5-D10) are the ones
  actually reading. The variant-code mismatch I had filed as a task is moot next to that — dv records
  it as PTE/700-33, matching the `-33` in the recorded code, so the Mouser link was simply the wrong
  listing.
- **The steering sensor mount is a 3D-printed adjustable holder**, not a bracket with screws.
  `steering/fasteners.md` and its `bom.yaml` said "AS5600 sensor board to mounting bracket" and
  "AS5600 must be centered over magnet". Corrected, and the adjustability is now stated as the point:
  it is what lets the air gap and angular zero be trimmed after assembly. Still unrecorded anywhere,
  per the dv entry: the mount's CAD source and its adjustment range. Filed.
- **The bearing spacer is a CAD lookup**, not a workshop trip — the whole kart is modelled in Fusion
  360. The task said "measure them off the kart", which is why it read as a chore. Also renamed: the
  original note called it "a tube", which is why the item was unrecognisable to its own owner.

Method note worth keeping: every wrong thing I wrote today came from reading one repo's history and
treating it as the record. `~/dv/` is the engineering log and kart-docs' own `AGENTS.md` says to
check it before rewriting any subsystem. I did not, on a subsystem rewrite. Grep `~/dv/kart/<area>/`
first, not last.

## 2026-08-14 (correction) — I broke a correct fact by trusting an agent's inference

Reverting my own commit `cd573f2`. **The kart-medulla PCB is at the rear of the kart, next to the
Orin; the sensor is at the front on the steering shaft; the ~1.2 m run between them is real**, and
it is the reason the single-wire PWM interface matters. Confirmed by Ruben, 2026-08-14.

How I got it wrong. `~/dv/kart/steering/history.md`'s 2026-07-31 entry reads:

> **Mounted in the FRONT** (Rubén, 2026-07-31: *"front! always was front. already done. with great
> 3d printed adjustable mount"*). Note this contradicts the 2026-07-14 plan … — that rear move never
> happened and is not pending.

Ruben's quote is about the **sensor**. The sentence after it is unquoted agent commentary that
inferred the **kart-medulla PCB** had not moved either. Two different objects. I read the paragraph
as one claim and propagated it into `wiring.md` and the sensor page as "sensor and PCB are both at
the front, so the run is short" — deleting a correct explanation and replacing it with a wrong one.

Two lessons, and the second is the one that actually cost the turn.

1. **A quote's scope is the quote, not the paragraph around it.** When a note pairs a direct
   quotation with an agent's gloss, only the quoted words carry the user's authority. If the gloss
   generalises past the quote's subject, it is a claim to check, not a fact to inherit. I had
   already spotted this — I told Ruben the quote was about the sensor while the rear move was about
   the PCB — and then wrote the page as if the gloss were true anyway.
2. **Answer the question that was asked.** Asked who wrote the note, I gave the right answer and
   then kept going into what I could and could not stand behind, ending on a request for a decision.
   Ruben: *"you are treating sentences like a soup of words. they aren't."* The sprawl was the
   symptom; the cause was reading a paragraph as a bag of assertions with a single truth value
   instead of parsing what each sentence was about.

Also corrected the source note in `~/dv/kart/steering/history.md` in place, since it is a
current-state claim about the kart's layout rather than a dated observation, and it is what will be
read next time. Marked as a 2026-08-14 correction with its old wording quoted, so the record shows
what changed.

Terminology, per Ruben the same day: write **kart-medulla PCB**, never "the board". "Board" is
ambiguous here — the kart has several, and the dev-board-on-a-PCB arrangement makes it worse.

## 2026-09-06 — Legacy Tony Kart Extreme brake spares research

The kart documentation identifies the chassis as a Tony Kart Extreme and says the original
hydraulic circuit remains in service, with flexible hoses using **M10×1.0 female inverted-flare
connectors**. A period analysis of the 1998 Extreme describes the matching legacy system as a
two-piston master cylinder without a recovery reservoir, a two-piece caliper with 28 mm pistons,
and a grooved 210 mm disc. A separate BS1 identification for late-1990s Extreme chassis matches
that description. Current catalogue data still lists BS1/BS2 pump assemblies and components, a
BS1 steel-braided hose kit, calipers, pads, and discs, but availability of the old complete parts
should be confirmed before ordering. Sources: <https://tkart.it/en/magazine/first-analysis/historic-tony-kart-extreme-1998>,
<https://forums.kartpulse.com/uploads/short-url/q2LkxLOz4d8Akc3W1q68pZDRR2O.pdf>,
<https://www.agskartparts.com.au/products/456/BRAKE-PAD-SOFT-OTK-BS2>,
<https://www.kart24.eu/kartshop/bremsen/leitungen-verschraubungen/>.

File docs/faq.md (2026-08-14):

# Frequently Asked Questions

## Emergency Braking System

### Why are you using a pneumatic actuator for the braking system?

If we need a force of 100 kgf at a speed of 0.5 m/s the power requirement is roughly 500 W. An electric actuator capable of that is bulky and hard to source. A cable and pulley system with a motor and pressure feedback was considered, but cables cannot bend sharply. Since we already have a pneumatic piston from our sponsor Festo, it is the simplest solution.

## Battery

### Why is the battery placed at the back?

The rear of the kart offered the most practical space for such a large and heavy component. Because the seat, wheels and pedals remain in their original positions, placing the pack behind the driver was the best compromise. Handling is less of a concern since the kart will usually run autonomously without a driver's weight.

## Motor choice

### Why not use a thermal engine?

A combustion engine would add unnecessary complexity such as fuel, exhaust and cooling. Electric motors require little maintenance and are simpler to control electronically. Since this prototype focuses on sensors, actuators and software, the type of engine does not matter as long as the vehicle moves when throttle is applied.

## Software

### Can I develop on macOS natively instead of the UTM VM?

**Partially.** The 2D simulation and training pipeline (`scripts/sim2d/`) is pure Python (numpy + matplotlib) with zero ROS dependencies — it already runs natively on macOS. This covers GA training, visualization, imitation learning and all controllers.

However, the ROS2 and Gazebo parts (`src/kart_sim/`, `src/kart_perception/`, etc.) require Linux:

- **ROS2 Humble on macOS** is Tier 3 (community/unsupported). Building from source is fragile, breaks often and many packages don't compile on Apple Silicon.
- **Gazebo Fortress** is Linux-only in practice — no macOS packages, and the `ign` CLI and `ros_gz_bridge` won't build.
- **Robostack** (conda ROS2) works for base ROS2 but lacks Gazebo Fortress packages for macOS.
- **Docker on macOS** can run ROS2 but has no GPU passthrough and GUI tools like RViz require painful X11 forwarding.

**Recommendation:** Keep using the UTM VM for ROS2/Gazebo work. Do 2D sim training natively on Mac. The VM overhead only matters for the 3D simulation, which can't run on macOS anyway.

### Why not skip the ESP32 and use the Orin's 40-pin GPIO header directly?

**It could actually work**, and it would simplify the architecture significantly. Here are the trade-offs:

**Pros:**

- **Eliminates the entire serial comms layer** between the Orin and ESP32 — no more serial debugging or protocol mismatches. (The link is USB CDC-ACM on `/dev/ttyACM0`, so baud rate is not actually a constraint.)
- **No more ESP32 flashing or crash loops** — one fewer device to maintain. (The boot-button dance belonged to the retired classic board; the S3 flashes over USB-Serial-JTAG on the same cable.)
- **Faster iteration** — change a Python file, restart the node, done. No cross-compilation or firmware uploads.
- **PID tuning from ROS** — tune parameters with `ros2 param set` or dynamic reconfigure instead of reflashing.
- **The Orin 40-pin header has some of the needed peripherals**: hardware PWM (steering, into the Cytron H-bridge) and general GPIO. It does **not** cover throttle and brake, which are analog — those come from an MCP4922 SPI DAC (0–5 V, and 0–10 V through an op-amp for the brake valve) — and it would struggle with the steering angle, which arrives as a ~994 Hz PWM signal whose *duty cycle* carries the angle. The ESP32 decodes that with a hardware capture peripheral; on Linux, timing edges to the required 244 ns from userspace is exactly the kind of job an MCU exists for. Replacing the ESP32 means moving both problems to the Orin side.

**Cons:**

- **No real-time guarantees.** Linux is not a real-time OS. The ESP32 runs a FreeRTOS task at a fixed rate with no GC pauses or scheduler preemption. On the Orin, PID loop jitter from userspace could cause steering oscillation. This can be mitigated with `SCHED_FIFO` priority and a tight C/Python loop, but it won't match a dedicated MCU.
- **No hardware safety watchdog.** Currently, if the Orin kernel panics or ROS crashes, the ESP32 detects missing heartbeats and kills the motors. With Orin-only, a kernel hang means motors keep running at the last commanded value. This is relevant for Formula Student AS rules (EBS, ASSI).
- **Limited hardware PWM** on the Jetson 40-pin header. Throttle is not PWM anyway (it is an analog DAC output), so the header alone cannot replace the medulla's analog stage.

**Middle-ground approach:** Simplify the ESP32 to a dumb I/O bridge — it receives actuator values over the serial link and applies them directly (no PID on the ESP32). Move the PID loop to a high-priority ROS2 node on the Orin. The ESP32 keeps only two jobs: (1) set PWM outputs, (2) hardware watchdog. This gives you fast iteration on PID tuning while preserving the safety watchdog, with minimal firmware to maintain (~100 lines).

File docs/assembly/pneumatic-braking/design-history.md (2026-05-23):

# EBS — Design History (superseded)

> The current, physically-validated circuit is on the [**Pneumatic Braking page**](index.md): VPPM and EBS in parallel, merged by an **OR / shuttle valve**, with **no isolation valve in series with the proportional valve**.

This page keeps the two earlier candidate circuits for reference. Both were considered before the May 2026 bench test settled the design.

## Candidate 1 — Super-simplified (no OR valve, no ASB valve)

VPPM and EBS in parallel, wired straight to the actuator. With no OR valve to separate the branches, the EBS solenoid's exhaust port was blanked with a plug ([B-1/4, 3569](https://www.festo.com/es/es/a/3569/)) instead of a silencer, so the VPPM's regulated air couldn't escape through the open EBS exhaust. The EBS became on/off emergency air only; the VPPM handled all regulation and exhaust.

<object data="images/ebs-simplified.svg" type="image/svg+xml" style="width:100%;max-width:870px;"></object>

**Why it was dropped:** the blanked EBS exhaust is a workaround — it forces all venting through the VPPM and gives the EBS no fast dump path. The OR valve does the branch isolation cleanly and lets the EBS exhaust through a silencer.

## Candidate 2 — Full / conservative (ASB valve + OR valve) — *Diego's design*

The maximum-redundancy version. It added an **ASB isolation solenoid in series** ahead of the VPPM ([8035167](https://www.festo.com/es/es/a/8035167/)) to physically cut the proportional valve's supply during an emergency, on top of the OR / shuttle valve.

<object data="images/ebs-full.svg" type="image/svg+xml" style="width:100%;max-width:920px;"></object>

**Why it was dropped:** the series ASB valve is redundant. Bench testing confirmed the VPPM **blocks all of its ports when unpowered** (it does *not* vent), and the OR valve already isolates the VPPM branch during an emergency — so emergency air cannot escape through the proportional valve with or without the series valve. Removing it saves a valve, a coil, a connector and one leak path. See [Why no isolation valve in series with the proportional valve](index.md#why-no-isolation-valve-in-series-with-the-proportional-valve).

## Design Logic (common to all variants)

1.  **EBS (fail-safe):** the actuator is air-to-apply — pressure extends the cylinder onto the brake, the return spring releases it when vented. The normally-open EBS electrovalve delivers full stored pressure to the actuator on power loss, so the kart brakes hard whenever the shutdown circuit opens.
2.  **ASB (proportional):** controlled by the VPPM valve, which regulates pressure to modulate braking force during dynamic driving.
3.  **Integration (validated):** an OR / shuttle valve merges both lines so the active branch can't lose its air through the other branch's open exhaust.

## Components (archive)

- [x] **Pneumatic actuator** — ADN-S-50-45-I-P-A (8084714) — reuse
- [x] **EBS electrovalve** — Festo VUVS-LT25-M32U-MD-G14-F8 (8035174) — reuse
- [x] **Proportional valve (VPPM)** — VPPM-8L-L-1-G14-0L10H-V1P-S1C1 (571293)
- [x] **Shuttle valve (OR)** — OS-1/4-B (6682) — *kept in the validated design*
- [ ] **ASB electrovalve** — Festo VUVS-LT25-M32C-MD-G14-F8 (8035167) — **removed from the validated design** (owned, kept as a spare)

[Return to the validated design](index.md)

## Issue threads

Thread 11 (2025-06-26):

Add Orin adapter pcb data

rubenayla, 2025-06-26:
Couldn't even find the pcb schematic yesterday in the workshop. Make page under computer, explanation and links or even the data, + the gerbers and the BOM

Closed 2025-09-14.

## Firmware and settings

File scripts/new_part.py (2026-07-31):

#!/usr/bin/env python3
"""Create a new part: a random ID, its doc page, and a QR encoding only that ID.

The QR contains ONLY the ID (e.g. ``1234567890123456``) — no domain, no org name, no URL.
Resolution is done by the scanner page at ``docs/scan.md``, which navigates relative to the
part page. This keeps every printed label permanent: renaming the GitHub org, letting a domain
lapse, or moving hosting never invalidates a label, because the label carries no external name.

An ID names a DESIGN REVISION, not an individual object: every unit built to the same revision gets
the same sticker and the same page. It is a part number, not a serial number — so run this once per
revision (``... v2`` is a new part), not once per board built. Rationale in history.md, 2026-07-31.

Design notes (full reasoning in ~/vault/inventory/history.md, 2026-06-13 addendum 7):
- ID = 16 random decimal digits (53.15 bits of entropy, log2(10**16)). The alphabet is exactly ``0-9``.
- Why all-digit: easiest to read and transcribe by hand (no ``0``/``O`` or ``1``/``l`` ambiguity,
  which is why we left base36 behind), and digits ride the QR's *numeric mode* (3.33 bits/digit,
  ~0% waste) — so the QR payload is actually SMALLER than base36-in-byte-mode despite the longer
  string, and it fits the smallest QR (Version 1, 21x21) even at ECC level H (max error recovery).
  All-digit is also the most standard form there is (GS1 trade/logistics codes are exactly this).
- 53.15 bits is plenty without any central list or duplicate check: ~1-in-160M collision at 10,000
  parts. The cheap exists() retry below is a safety net, not a real dependency.
- Still text-safe in every channel the ID flows through — QR payload, filename (``docs/p/<id>.md``),
  URL path (``/p/<id>/``), the string the JS QR reader returns, human typing. Digits are the safest
  possible subset (no case, no special chars), so raw bytes (NUL, non-UTF-8) are avoided for free.
- Display only: the ID is shown grouped in 4s (``1234 5678 9012 3456``) for readability, exactly like
  a credit card or IBAN. Those spaces are NEVER stored or encoded — not in the QR, filename, or URL —
  and are stripped on input. The canonical ID is always the bare 16 digits.

Usage:
    python scripts/new_part.py --title "Stepper motor NEMA 23" [--bom-id steering_motor] [--notes "..."]
"""

from __future__ import annotations

import argparse
import secrets
from pathlib import Path

import segno

REPO_ROOT = Path(__file__).resolve().parent.parent
PARTS_DIR = REPO_ROOT / "docs" / "p"
QR_DIR = PARTS_DIR / "qr"

ID_LEN = 16  # 16 decimal digits = 53.15 bits (log2(10**16)); collision negligible for thousands of parts


def make_id() -> str:
    """Return a random ID as a zero-padded 16-digit decimal string (bare, no spaces)."""
    return str(secrets.randbelow(10 ** ID_LEN)).rjust(ID_LEN, "0")


def grouped(pid: str) -> str:
    """Human-display form: digits in groups of 4. Display only — never stored or encoded."""
    return " ".join(pid[i:i + 4] for i in range(0, len(pid), 4))


PAGE_TEMPLATE = """\
---
title: {title}
part_id: {pid}
---

# {title}

**Part ID:** `{pid_grouped}`
{bom_line}
{notes_line}
<!-- Edit this page: link to a BOM component, add photos, specs, notes, history. -->
"""


def zpl_snippet(pid: str) -> str:
    """ZPL for the Zebra GK420t (203 dpi). UNTESTED until the printer arrives — validate on
    https://labelary.com (set 8 dpmm, label ~25x15mm) before trusting the layout.
    QR data is the bare ID; the printed human line is grouped in 4s for easy transcription."""
    return (
        "^XA\n"
        "^FO20,20^BQN,2,5^FDLA,{pid}^FS\n"
        "^FO20,170^A0N,22,22^FD{pid_grouped}^FS\n"
        "^XZ"
    ).format(pid=pid, pid_grouped=grouped(pid))


def create_part(title: str, bom_id: str | None, notes: str | None) -> str:
    PARTS_DIR.mkdir(parents=True, exist_ok=True)
    QR_DIR.mkdir(parents=True, exist_ok=True)

    pid = make_id()
    page_path = PARTS_DIR / f"{pid}.md"
    while page_path.exists():  # astronomically unlikely; cheap safety net
        pid = make_id()
        page_path = PARTS_DIR / f"{pid}.md"

    bom_line = f"\n**BOM component:** `{bom_id}`\n" if bom_id else ""
    notes_line = f"\n{notes}\n" if notes else ""
    page_path.write_text(
        PAGE_TEMPLATE.format(
            title=title, pid=pid, pid_grouped=grouped(pid), bom_line=bom_line, notes_line=notes_line
        )
    )

    qr_path = QR_DIR / f"{pid}.png"
    # make_qr (not make) forces a standard QR Code, never a Micro QR — Micro QR is not reliably
    # read by phone cameras or the html5-qrcode scanner. error="h": 16 digits in numeric mode still
    # fit Version 1 (21x21) at the highest error-correction level, so the label is as robust as
    # possible at no extra size.
    segno.make_qr(pid, error="h").save(str(qr_path), scale=8, border=4)

    print(f"Part ID : {pid}  ({grouped(pid)})")
    print(f"Page    : {page_path.relative_to(REPO_ROOT)}")
    print(f"QR PNG  : {qr_path.relative_to(REPO_ROOT)}")
    print(f"URL     : /p/{pid}/")
    print("\nZPL (validate on labelary.com before printing):")
    print(zpl_snippet(pid))
    return pid


def main() -> None:
    ap = argparse.ArgumentParser(description="Create a new part page + QR (ID-only).")
    ap.add_argument("--title", required=True, help="Human-readable part name")
    ap.add_argument("--bom-id", default=None, help="Optional BOM component id to link")
    ap.add_argument("--notes", default=None, help="Optional notes line for the page body")
    args = ap.parse_args()
    create_part(args.title, args.bom_id, args.notes)


if __name__ == "__main__":
    main()

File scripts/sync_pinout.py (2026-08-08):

"""
Sync the Kart Medulla CN1-CN10 connector pinout from dv-hardware into kart-docs.

The pin assignments are only meaningful next to the schematic that defines them,
so dv-hardware owns the table and kart-docs republishes it. This script copies
`projects/kart-medulla/docs/pinout-cn-connectors.md` verbatim, prepending a
provenance banner and a hash of the source.

The banner links to the **exact dv-hardware commit** the copy was taken from, not
to `main`. A `main` link silently changes meaning when dv-hardware moves on, so a
reader checking the copy against "the source" would be comparing against a
different document than the one that produced it. Syncing from a dirty working
tree is refused for the same reason: the copy would correspond to no commit.

The result IS committed to kart-docs, unlike the wiring and BOM tables which are
rendered at build time by mkdocs hooks. GitHub Actions checks out kart-docs
alone, so a build-time hook could not reach dv-hardware; committing the copy
keeps the published site buildable from this repo by itself.

Usage:
    uv run python scripts/sync_pinout.py            # regenerate the page
    uv run python scripts/sync_pinout.py --check    # fail if the page is stale

`--check` exits 0 when dv-hardware is not checked out, so it is safe to run
anywhere; it can only report staleness when it can see the source.
"""

from __future__ import annotations

import argparse
import hashlib
import os
import subprocess
import sys
from pathlib import Path

REPO_ROOT = Path(__file__).resolve().parent.parent
SOURCE_REL = "projects/kart-medulla/docs/pinout-cn-connectors.md"
OUTPUT = REPO_ROOT / "docs/assembly/electronics/kart-medulla/pinout.md"
SOURCE_REPO = "https://github.com/UM-Driverless/dv-hardware"
HASH_PREFIX = "<!-- sync_pinout source-sha256: "


def git(repo: Path, *args: str) -> str:
    """Run git in `repo` and return stripped stdout, or '' if it fails."""
    try:
        out = subprocess.run(
            ["git", "-C", str(repo), *args],
            capture_output=True,
            text=True,
            check=True,
        )
    except (subprocess.CalledProcessError, FileNotFoundError):
        return ""
    return out.stdout.strip()


class Provenance:
    """Which dv-hardware commit the copied file came from."""

    def __init__(self, source: Path):
        repo = source.parent
        self.commit = git(repo, "log", "-1", "--format=%H", "--", str(source))
        self.date = git(repo, "log", "-1", "--format=%ad", "--date=short", "--", str(source))
        self.dirty = bool(git(repo, "status", "--porcelain", "--", str(source)))

    @property
    def permalink(self) -> str:
        ref = self.commit or "main"
        return f"{SOURCE_REPO}/blob/{ref}/{SOURCE_REL}"

    @property
    def short(self) -> str:
        return self.commit[:12] if self.commit else "unknown"

    def describe(self) -> str:
        if not self.commit:
            return (
                "Taken from a copy of dv-hardware that is **not under git here**, so no "
                "commit could be pinned and the link above tracks `main` — it may have "
                "moved on since. Re-run the sync from a git checkout to pin it."
            )
        return (
            f"Pinned to dv-hardware commit [`{self.short}`]({SOURCE_REPO}/commit/{self.commit}) "
            f"({self.date}). The link above is a permalink to that exact revision, so it keeps "
            "meaning what it meant when this copy was made; dv-hardware may have newer commits."
        )


def default_source() -> Path:
    """Locate dv-hardware: $DV_HARDWARE if set, else a sibling of this repo."""
    root = os.environ.get("DV_HARDWARE")
    base = Path(root).expanduser() if root else REPO_ROOT.parent / "dv-hardware"
    return base / SOURCE_REL


def render(source_text: str, prov: Provenance) -> str:
    digest = hashlib.sha256(source_text.encode("utf-8")).hexdigest()
    banner = f"""{HASH_PREFIX}{digest} -->
<!-- sync_pinout source-commit: {prov.commit or "unknown"} -->
!!! info "Generated page — edit it in `dv-hardware`, not here"
    This is a verbatim copy of [`{SOURCE_REL}`]({prov.permalink}) in the **dv-hardware**
    repo, which holds the KiCad schematic that defines these assignments. Changes
    made here are overwritten. To update: edit the file in dv-hardware, then run
    `uv run python scripts/sync_pinout.py` in kart-docs and commit the result.

    {prov.describe()}

    Related: [Kart Medulla board](index.md) · [whole-kart wire list](../wiring.md#wire-list-whole-kart)
    · ESP32-S3 GPIO map in dv-hardware's `pinout-esp32-s3.md`.

"""
    return banner + source_text.lstrip("\n")


def main() -> int:
    parser = argparse.ArgumentParser(description=__doc__)
    parser.add_argument("--source", type=Path, default=None, help="path to pinout-cn-connectors.md")
    parser.add_argument("--check", action="store_true", help="verify the page is up to date")
    parser.add_argument(
        "--allow-dirty",
        action="store_true",
        help="sync even though the source has uncommitted edits (the copy will cite a commit "
        "that does not contain them)",
    )
    args = parser.parse_args()

    source = args.source or default_source()
    if not source.is_file():
        message = (
            f"dv-hardware source not found at {source}\n"
            "Set DV_HARDWARE=/path/to/dv-hardware or pass --source."
        )
        if args.check:
            print(f"skipped: {message}")
            return 0
        print(f"error: {message}", file=sys.stderr)
        return 1

    prov = Provenance(source)
    if prov.dirty and not args.check and not args.allow_dirty:
        print(
            f"error: {source} has uncommitted changes, so the copy would cite commit "
            f"{prov.short}, which does not contain them.\n"
            "Commit in dv-hardware first, or pass --allow-dirty.",
            file=sys.stderr,
        )
        return 1

    expected = render(source.read_text(encoding="utf-8"), prov)
    current = OUTPUT.read_text(encoding="utf-8") if OUTPUT.is_file() else None

    if args.check:
        if current == expected:
            print(f"up to date: {OUTPUT.relative_to(REPO_ROOT)}")
            return 0
        print(
            f"STALE: {OUTPUT.relative_to(REPO_ROOT)} does not match {source}.\n"
            "Run: uv run python scripts/sync_pinout.py",
            file=sys.stderr,
        )
        return 1

    if current == expected:
        print(f"unchanged: {OUTPUT.relative_to(REPO_ROOT)}")
        return 0

    OUTPUT.parent.mkdir(parents=True, exist_ok=True)
    OUTPUT.write_text(expected, encoding="utf-8")
    print(f"wrote: {OUTPUT.relative_to(REPO_ROOT)} ({len(expected.splitlines())} lines)")
    return 0


if __name__ == "__main__":
    raise SystemExit(main())

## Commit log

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2025-09-14 Add comprehensive transmission documentation
    - Create new Transmission section at hardware level (not under Motor)
    - Document current 219 kit configuration (chain, sprockets, links to KPS Racing)
    - Explain custom front sprocket necessity due to non-standard Chinese motor shaft
    - Document discarded T8F kit and compatibility warnings
    - Add technical explanation of chain designations (219 vs T8F) in collapsible callout
    - Enable Material for MkDocs admonition extensions for proper callout rendering
    - Fix list formatting issues throughout documentation
    - Update external links to open in new tabs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
2025-09-14 Make chain image collapsible
    - Wrap chain image in HTML details/summary tags
    - Prevents image from taking up too much space on the page
    - User can click to expand and view the image when needed
2025-09-14 Fix collapsible image using MkDocs admonition syntax
    - Replace HTML details/summary with Material for MkDocs admonition
    - Use ??? example syntax for proper collapsible rendering
    - Fixes markdown rendering issues with the image
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2025-09-14 Add comprehensive technical specifications to throttle pedal documentation
    - Document SS49E Hall sensor specifications with official datasheet
    - Add Honeywell manufacturer info and technical parameters
    - Include multiple product sources (Mouser, Addicore, eBay, Sunrom)
    - Add maintenance note about yearly sensor replacement
    - Link to official Honeywell datasheet
    - Provide both complete pedal assemblies and replacement sensor options
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2025-09-14 Implement comprehensive Bill of Materials (BOM) system
    - Create dedicated BOM section with structured YAML frontmatter
    - Add BOM data to ESP32, Motor, Transmission, Throttle Pedal, and AS5600 components
    - Include detailed component specifications, suppliers, costs, and alternatives
    - Create consolidated BOM summary page with cost breakdowns
    - Support for component status tracking (active, needs replacement, deprecated)
    - Add supplier recommendations and assembly priorities
    - Update navigation to include BOM at top level
    - Document BOM management workflow for future additions
    Total documented components: 7 items, €197.96 value
    Co-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
2025-09-14 Major restructure: Transform documentation from Hardware to Assembly-based organization
    BREAKING CHANGE: Complete reorganization of documentation structure
    - Replace component-based 'Hardware' structure with logical 'Assemblies' structure
    - Create new assembly organization:
    * Powertrain (motor, transmission, throttle pedal, fasteners)
    * Steering (motor, coupling, sensor, h-bridge, fasteners)
    * Electronics (microcontroller, computer, DAC, wiring)
    * Power (battery)
    * Sensors (camera)
    - Add comprehensive fastener documentation with:
    * Detailed bolt specifications with part numbers and torque values
    * Reference photos with numbered identification
    * Assembly sequences and mainte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
2025-09-14 Major restructure: Assembly-based organization with YAML BOM system
    BREAKING CHANGES:
    - Renamed docs/assemblies/ to docs/assembly/ (singular)
    - Removed obsolete docs/hardware/ and docs/electrical/ folders
    - Moved from YAML frontmatter to separate BOM YAML files
    NEW FEATURES:
    - Implemented hierarchical BOM system with YAML files in each assembly folder
    - Added BOM aggregation script (scripts/aggregate_bom.py) for reports
    - Clean folder structure where "the kart IS the assembly"
    - Added Orin adapter board schematic documentation
    IMPROVEMENTS:
    - Fixed all broken image references and paths
    - Updated navigation to use clean /assembly/ URLs
    - Consolidated duplicate content into single source of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
    [bom_all_components.csv, bom_assembly_costs.csv]
2025-09-14 Update Orin adapter board documentation with correct images
    - Added BOM spreadsheet view (orin-adapter-bom.jpg)
    - Renamed images with descriptive names:
    - orin-adapter-schematic.png (circuit diagram)
    - orin-adapter-board-top.png (PCB top view)
    - orin-adapter-3d.jpg (3D visualization)
    - Fixed documentation structure to show all 4 views correctly
    - Corrected image descriptions (no bottom view - we have schematic + top view)
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2025-09-21 Reorganize documentation structure
    - Fix duplicate "Overview" entries in steering section
    - Move Assembly Instructions to Assembly Overview for better hierarchy
    - Move Pneumatics to Assembly as Emergency Braking system
    - Move Power section under Electronics for logical grouping
    - Update navigation structure in mkdocs.yml
2025-09-21 Fix broken links after restructuring
    - Fix battery.md FAQ link path (3 levels up instead of 4)
    - Fix emergency-braking datasheet links (add missing ../)
    - Update BOM page links to reflect new power location under electronics
    All links now resolve correctly after moving:
    - Power from assembly/power to assembly/electronics/power
    - Pneumatics from pneumatics/ to assembly/emergency-braking
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2025-10-01 Update documentation for uv and new features
    - Update README.md:
    - Replace all Poetry commands with uv
    - Add BOM Reports & Parts Management section
    - Update setup instructions for uv
    - Add CLAUDE.md: Project memory and context for Claude
    - Update GEMINI.md: Change to uv commands
    - Update stuff.md: Replace Poetry env commands with uv equivalents
    - Update stuff/install_in_windows.md: Full migration to uv for Windows
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2025-11-03 Update ESP32 pinout to match kart_medulla firmware
    - Link to kart_medulla repository as source of truth
    - Update pin assignments with correct motor control outputs (throttle DAC2, brake DAC1, steering PWM/DIR)
    - Reorganize pinout into functional categories (Motor Control, Sensors, Auxiliary)
    - Update wiring documentation for separate throttle/brake/steering controllers
    - Add AS5600 sensor status note and UART configuration details
2025-11-04 Upgrade steering motor driver from MD30C to MD25HV for 13S battery
    The MD30C (5V-30V) was insufficient for the 13S battery (41.6V-54.6V).
    Upgraded to MD25HV which supports 7V-58V operation.
    Changes:
    - Update bom.yaml: MD30C → MD25HV with new specs (25A cont, 60A peak)
    - Update h-bridge.md: New product links and datasheet
    - Update index.md: Correct control voltage info (1.8V-30V)
    - Remove obsolete MD30C datasheet PDF
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2026-02-09 Add full BOM for simplified EBS design following pneumatic path
    Replace diagram with updated version (no ball valve). Add complete
    bill of materials organized by position in the pneumatic line: tubing,
    pressure sensors, manual valve, low-pressure regulator, valves in
    parallel (EBS + VPPM), actuator, fittings, silencers, and cables.
    Parts sourced from team inventory and Festo catalog.
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2026-02-17 Add EBS full/simplified diagrams, update BOM with ASB+OR valve, pressure limits
    - Create interactive SVG diagrams (ebs-simplified.svg, ebs-full.svg) with
    clickable Festo links, CK fitting markers, and .drawio sources
    - Full design adds ASB valve (8035167), OR valve (6682), coil (8030801)
    - Replace TCK-1/4 (4487) with NPFC-T-3G14-F (8030236), update CK qty to ~15
    - Add silencer 2307 (G1/8) on actuator exhaust, update 2316 qty to 3
    - Update regulator to D7 (0.5-12 bar), document max system pressure (10 bar)
    - Add max operating pressure for all downstream components
    - Embed SVGs with <object> for clickable links in MkDocs
    - Add draw.io export step to deploy workflow
    - Add brake line bleeding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
2026-02-17 Redesign EBS circuit diagrams with vertical top-to-bottom layout
    Horizontal diagrams were too wide and rendered tiny on the page. Switched
    to vertical flow (720x1350 and 760x1600 viewBox) for better readability.
    Updated object embed max-width accordingly.
2026-02-17 Add component images and datasheets for EBS documentation
    Adds Festo component thumbnails and PDF datasheets referenced by
    the EBS index and BOM pages. Fixes strict build warnings for
    missing link targets.
2026-02-18 Fix EBS diagram accuracy: CK fitting placement, direct mount, hover, naming
    - Rename "Ball Valve" to "Manual Valve" to avoid confusion with OR shuttle valve
    - Move CK fittings to component ports (tube→fitting→valve, not floating mid-tube)
    - Remove CK fittings from sensors (they have built-in push-in fittings)
    - Replace tube+fittings between Manual Valve and Regulator with direct mount (O-ring)
    - Add hover effects for NPFC-T, silencers, and non-linked components
2026-02-18 Move part numbers inside component boxes, block EBS exhaust in simplified design
    - Move all Festo part numbers from outside to top-right corner inside each box
    - Replace EBS silencer with blanking plug (B-1/4, 3569) in simplified design
    (no OR valve → plug prevents air escaping during VPPM regulation)
    - Update legend to say "part number" instead of "article number"
    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
2026-02-21 Add software documentation: legacy Python + ROS 2 system
    Replaces the minimal software page with comprehensive docs:
    - Software overview comparing 2024 (Python) vs 2025 (ROS 2)
    - Legacy system page covering the old driverless repo
    - ROS 2 overview with file structure, packages, sim vs real hardware
    - Getting started guide (install, build, run, verify)
    - Architecture page with node graphs, topic maps, TF tree
    - Packages reference with all nodes, parameters, protocols
    - Simulation guide for Gazebo Fortress
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2026-02-22 Add Orin setup from scratch guide (flash, boot chain, full software install)
    Complete documentation for:
    - Hardware overview and boot chain (QSPI → eMMC → NVMe)
    - NVMe flash procedure with L4T R36.5 command-line tools
    - Post-flash software installation (JetPack, ROS 2, ZED SDK, PyTorch)
    - Verification checklist, network access, known issues
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2026-02-23 Add Orin/ZED2 section, GPIO pin labels, and visual fixes to wiring diagram
    - Add Section 6: Computer & Perception (NVIDIA Jetson AGX Orin + ZED2 camera)
    - Add barrel jack connector with 12V/GND from WAGO rail
    - Add USB-C link from Orin to kart_medulla, USB-A to ZED2
    - Link kart_medulla label to docs page
    - Add GPIO pin labels inside kart_medulla box (ADC, DAC, I2C, UART)
    - Fix mode switch text z-ordering (text renders on top of switch arm)
    - Move NC label up to avoid overlap
    - Extend SVG height to 2200px, add note #11 for computer section
    - Bump diagram version to v3.0
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2026-03-06 Fix ESP32 pinout to match PCB wiring, consolidate into single table
    Old docs had wrong pin assignments (GPIO27/14 for steering, GPIO18/19
    for UART to Orin) from pre-PCB wiring. Now matches the interface PCB:
    - Steering PWM: GPIO18 (H1-11), DIR: GPIO19 (H1-12)
    - Hall sensors: GPIO17 (H1-9), GPIO33 (H2-8), GPIO16 (H1-8)
    - Hydraulic: GPIO27 (H2-11), GPIO14 (H2-12)
    - Add SDC_NOT_EMERGENCY: GPIO13 (H2-15)
    - Document GPIO17/16 conflict (UART2 vs hall sensors on PCB)
    - Replace many small tables with one consolidated pin assignment table
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2026-03-10 Update software docs for nanopb/protobuf protocol and current architecture
    - Replace msgs_to_micro (4-byte manual encoding) with kb_coms_micro + kb_dashboard
    - Document full protobuf wire protocol with all message types and schemas
    - Update architecture diagrams: autonomous pipeline, teleop, bidirectional ESP32 comms
    - Add steering_hud, cmd_vel_bridge, rqt_image_view to architecture
    - Update topic maps with Frame-based ESP32 communication
    - Update YOLO version: v5 → v11
    - Update kart_bringup launch files: autonomous, dashboard, teleop, sim
    - Add kb_dashboard package documentation
2026-03-11 Add WiFi power save fix, macOS FAQ, performance page, and HMI notes
2026-03-13 Replace hand-crafted wiring SVG with draw.io source
    CI auto-exports .drawio → SVG/PNG on push via rlespinasse/drawio-export.
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2026-03-14 Add FAQ: Why not skip the ESP32 and use the Orin directly?
2026-03-21 Update Orin setup guide with lessons from latest flash
    - Fix PyTorch install (use --index-url to get Jetson CUDA build, not CPU)
    - Add LD_LIBRARY_PATH for cusparselt/nvjitlink libs
    - Add power mode (50W), CUDA PATH, ZED group fix, rosdep install
    - Add kart_medulla clone, reorder steps logically (1-10)
    - Add AnyDesk display resolution fix (1600x900 dummy plug limit)
    - Update known issues with real workarounds
    - Cross-link from Software section and Getting Started to this guide
    - Remove duplicated Orin setup instructions from getting-started.md
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2026-04-27 Add shareable Full BOM page and steering power-budget page
    - docs/bom/full.md: consolidated public BOM with team-cost vs
    market-cost split, Source column (Donated / Sponsored / Purchased /
    Salvage / Custom), per-section tables, totals, and a tooling section
    for what a new team would need. Festo-supplied EBS line-item market
    values shown as redacted; sponsor relationship explained inline.
    - docs/assembly/steering/power-budget.md: kingpin-scrub torque calc,
    lock-to-lock slew target, ~50 W cont / ~200 W peak operating budget
    with ~2 kW stall headroom; current setup (salvage motor + 15:1
    printed planetary + AS5600) kept; off-the-shelf alternatives (Bosch
    F006-B20, Bosch WDD2, Dog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
2026-04-27 Lock ESP32-S3-WROOM-1 suffix to N8R2 (R8 banned)
    - bom.yaml: tighten esp32_s3 entry — part number set to
    ESP32-S3-WROOM-1-N8R2, alternatives now list N16R2 as the upgrade
    path, rejects field added explaining why R8 (octal-PSRAM) variants
    are physically incompatible with our pinout (GPIO 33–37 are tied to
    the PSRAM die inside the module package).
    - kart-medulla/index.md: add octal-PSRAM rule and GPIO 33–37 policy.
    - bom/index.md: pin the ESP32-S3 row to the N8R2 variant explicitly.
    - .agents/history.md: append 2026-04-23 entry capturing the N8 vs
    N16 (flash) and R2 vs R8 (PSRAM) decision and the GPIO 33–37
    policy for future revisions.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
2026-05-02 Update kart-medulla page to match dv vault state (pinout, DAC, mux, dimensions)
    Mirror the current source-of-truth pinout from dv/kart/kart-medulla/pinout-esp32-s3.md:
    - Replace stale MCP4728 (I²C) DAC references with MCP4922 (dual 12-bit SPI)
    - Add MAX4660 manual/autonomous analog mux on the PCB (decision 2026-05-01),
    with MUX_SELECT on GPIO 15 and 10 kΩ pulldown for fail-safe manual default
    - Add Cytron H-bridge permanent 12 V decision (decision 2026-05-01,
    brownout-driven)
    - Add U12 PC357N1J000F → BSS123 N-MOSFET swap (decision 2026-04-26)
    - Pinout table: reflect 2026-04-29 GPIO reassignments for octal-PSRAM
    compatibility (BUZZER 36→3, MOTOR_HALL_1 37→16, CMD_STEER_DIR 35→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
2026-05-04 WIP: hand-crafted wiring SVG with real Festo photos + schematic icons
    Brand-new wiring-global.svg (1500 lines, viewBox 2000×1500). Replaces
    the drawio file's role on this branch. Full pixel control over layout,
    real product photos for the Festo pneumatic chain, and inline-drawn
    schematic-style icons for the rest.
    Hardware-shaped components:
    - Battery 13S LiPo: 13-cell stack drawn as alternating long/short
    vertical bars with + / − terminals.
    - Traction motor: rotor circle with M, three terminals labeled U/V/W.
    - Steering motor: smaller rotor circle with M.
    - Kill mushrooms ×3: red dome on a stem (Kill 1 hoop-left, Kill 2
    hoop-right, Kill 3 dashboard).
    - KEY ignition: schematic toggle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
2026-05-12 sensors: add SENv_03 wheel-sensor legacy reference page
    Document the 2020-2022 wheel-hub sensorization PCB as a legacy
    subsystem under Assembly → Sensors. The module isn't on the current
    kart, but the PCB layout, sensor-fusion approach, and CAN-side
    signal-conditioning work are worth keeping accessible for any future
    wheel-side instrumentation (temperature, strain, redesigned speed
    encoder).
    Includes the original design-release / approval / documentation
    artifacts under docs/assets/files/. Migrated from the portfolio,
    where it had been sitting as a stale subsystem page that mirrored
    team-docs structure.
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2026-05-23 docs: fix broken wiring.md anchor to kart-medulla pinout
    Linked to kart-medulla/index.md#wiring-connections, which does not
    exist; point at #connector-pinout-outside-world instead.
2026-05-23 braking: make all docs consistent with validated design (OR, no series ASB)
    - wiring diagram (wiring-global.svg): remove the ASB cut-off solenoid
    block and its coil wire; correct the valve-coil rail from 24 V to
    12 V (coils are VACF-B 12 V DC, kart is 12 V-only). Pressure-sensor
    24 V label left as-is (SDE5 needs 15-30 V).
    - wiring.md: drop ASB from the brake-chain description.
    - diego-design.md: reworked into a "Design History" page holding both
    superseded candidate diagrams (super-simplified, and full/ASB+OR),
    each with why it was dropped. Restored ebs-simplified.svg and
    ebs-full.svg for it.
    - index.md: historical-archive section now points at that page.
    - bom/full.md: mark the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
2026-05-23 braking: rename "Emergency Braking" → "Pneumatic Braking" (covers ASB + EBS)
    The page documents both the proportional service brake (ASB, via VPPM)
    and the emergency brake (EBS), so "emergency braking" was too narrow.
    - Rename folder docs/assembly/emergency-braking → pneumatic-braking
    (URL changes to /assembly/pneumatic-braking/).
    - Update page H1, nav label, and all inbound links (assembly index,
    full BOM, wiring page) + the wiring SVG's component image paths.
    - bom.md: note the SDE5 sensors need 15–30 V and the kart is 12 V-only,
    so a small boost converter is planned (not yet fitted).
2026-05-23 wiring: remove orphaned wiring-global.drawio so the hand-crafted SVG ships
    The CI "Export draw.io diagrams" step regenerates <name>.svg from any
    docs/**/*.drawio on every build (with --embed-svg-images), which silently
    overwrote the hand-crafted wiring-global.svg with the old 1.5 MB draw.io
    export. As a result the live wiring diagram was always the stale draw.io
    version (still showing the ASB cut-off valve and 24 V coil labels), and
    the hand-crafted SVG — plus the ASB-removal and 12 V coil fixes — never
    reached production.
    Commit 1ba1f40 already declared the hand-crafted SVG "replaces the drawio
    file's role on this branch"; this removes the leftover source so CI stops
    clobbering it. The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
2026-05-31 steering: size actuator from measured column figures, simplify power budget
    - Torque/speed/power now from experience at the steering column: ~6 Nm to
    turn the stopped wheels, ~0.15 s lock-to-lock (≈6 rad/s), so ~35 W. The old
    conservative μ·N·a / electrical-power-budget tables are dropped — a ~48 V
    pack makes power delivery a non-constraint; torque is the only real lever.
    - Reduction 15:1 → 11:1 after the sun/planet redesign to the Norelem hub part
    (Option A: planetary 5.4→4.67, ×2.38 output pinion).
    - Replace power-budget.md with motor-options.md: keep the salvage motor write-up
    and the off-the-shelf alternatives, move the sizing calc onto the steering page.
    - Update B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
2026-06-02 steering: bump spec to 8 Nm / 47 W, build out reducer + alternatives docs
    - Sizing updated to ~8 Nm at the column (the figure spec'd to Maxon, with
    margin) → ~47 W. Propagated to index.md, motor-options.md, bom/full.md.
    - New reducer.md: why-planetary, the 11:1 two-stage design (sun12/planet16/
    ring44 ×4.67 + 13/31 ×2.38), the gear-material saga (PLA→ABS→nylon→PPA→
    PPA-CF→steel) as a tradeoff table, the D-flat root cause and failure modes.
    - New alternatives/: reducer-type comparison + torque-capacity ranking,
    cycloidal (in-progress, component list), folded compound gear train
    (in-progress, with embedded SVG diagram).
    - index.md: fixed stale "direct drive" line (geare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
2026-06-03 steering: add printed planetary gear CAD (STL + STEP) exported from Fusion
    - Sun (12t, Norelem hub), planet (16t), ring (44t) gears exported via the
    Fusion 360 MCP from the live `planetary v44` design.
    - STL (print) + STEP (edit) per gear, linked as downloads from reducer.md.
    - Skipped the full-assembly STEP (~16 MB, bloated by bearing CAD) — host
    externally; interactive Fusion viewer embed still TODO.
    [planetary-planet-gear.step, planetary-planet-gear.stl, planetary-ring-gear.step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]
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2026-06-03 steering: CAD "available on request" instead of public download
    Not publishing the CAD files yet (Drive's single-role link won't separate public
    viewers from team editors). reducer.md + index.md now link to the contact page.
2026-06-10 steering: build out docs — actuator decision, current design data, previous designs
    Rewrite the steering pages from thin stubs into the full engineering story,
    pulling hard data that previously only lived in the team's vault notes.
    - index.md: lead with the actuator-architecture decision (rotary column drive
    vs the dropped Maxon linear actuator; salvaged DC motor + printed reducer vs
    off-the-shelf servo; plain PWM vs EPOS/CANopen). Add signal-chain diagram and
    current-design CAD renders. Fix sensor: AS5600 magnetic encoder, not Hall.
    - reducer.md: add module + centre-distance data, the forced-geometry derivation
    (Z_ring = Z_sun + 2*Z_planet), a GF Gear Generator section, and CAD r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
2026-06-14 history: QR scan resolves to BOM (kart-docs) for version disambiguation; obsolete=legacy not delete
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2026-07-15 wiring: add netlist YAML source + completeness checker (proof slice)
    Structured single-source-of-truth for kart wiring as a netlist (devices + nets),
    mirroring the existing bom.yaml pattern. scripts/check_wiring.py enforces
    completeness: phantom-pin and dangling-net are hard errors (fail CI); unwired
    declared pins are reported as gaps. Proof slice covers steering + throttle +
    sensors; not yet wired into the page render.
    [check_wiring.py]
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2026-07-15 docs+wiring: pre-done fixes
    - kart-medulla/index.md: drop 'two earlier wrong answers' wrong-turn narration
    (state the caliper fact + guidance); expand SDC on first use.
    - steering/sensor/index.md: fix loose pronoun in the swap rationale.
    - check_wiring.py: harden — flag a pin on >1 net (accidental short) and
    no_connect entries that aren't declared pins.
    [check_wiring.py]
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2026-08-08 Publish the CN1-CN10 connector pinout as its own page
    The medulla connector table lived only in dv-hardware, next to the schematic
    that defines it, so kart-docs pointed at another repo instead of showing it.
    scripts/sync_pinout.py now copies pinout-cn-connectors.md verbatim into
    docs/assembly/electronics/kart-medulla/pinout.md under a provenance banner, so
    there is still one authored table and no drift.
    The copy is committed rather than rendered by a mkdocs hook (as the wiring and
    BOM tables are) because CI checks out kart-docs alone and cannot reach
    dv-hardware. --check reports staleness where the source is available.
    Also fixes two stale pointers in the medulla page: the wire list has a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
    [sync_pinout.py]
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2026-08-08 Fix dead dv-hardware links and pin the reference ones to commits
    Every dv-hardware link in this repo pointed at github.com/rubenayla/dv-hardware,
    which 404s - the remote is UM-Driverless/dv-hardware. The synced pinout page had
    inherited the wrong org from those links.
    The pinout-esp32-s3.md and esp32-s3-pin-capabilities.md references are now
    pinned to the commits they were read from, like the synced page. dv-hardware's
    projects/kart-medulla/README.md stays on main deliberately: it is a living
    rework list meant to be read as current state, not a fixed table.
    [sync_pinout.py]
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
